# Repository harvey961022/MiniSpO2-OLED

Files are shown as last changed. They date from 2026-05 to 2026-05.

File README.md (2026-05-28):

# ESP32 血氧心率 OLED 顯示器

這是一個用 ESP32 做的小型血氧心率顯示器。

目前螢幕是 0.96 吋 128x64 I2C OLED

* SpO2 血氧
* BPM 心率
* 感測器狀態
* 手指是否有放好

## 使用的硬體

* ESP32 / NodeMCU-32S
* MAX30102 或 MAX30105 血氧心率感測器
* 0.96 吋 OLED 顯示幕
  * 128x64
  * I2C / IIC
  * 4 Pin
  * 常見 SSD1306 驅動
* 杜邦線

## 接線方式

OLED 跟 MAX30102 / MAX30105 都是 I2C，所以可以接在同一組 SDA / SCL 上。

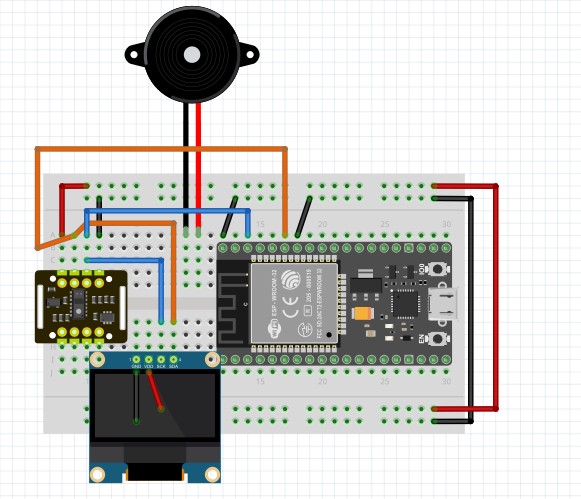
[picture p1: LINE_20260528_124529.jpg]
ESP32 血氧心率 OLED 接線圖


ESP32 常用接法：

```text
OLED VCC  -> 3V3 或 5V
OLED GND  -> GND
OLED SDA  -> GPIO 21
OLED SCL  -> GPIO 22

MAX30102 VCC -> 3V3 或 5V
MAX30102 GND -> GND
MAX30102 SDA -> GPIO 21
MAX30102 SCL -> GPIO 22
```

如果你的模組標示不是 SDA / SCL，而是其他名字，基本上也是照 I2C 腳位去接。

接線圖原始檔可以下載 `Oxygen_Saturation.fzz`，使用 Fritzing 開啟後可以自行修改。

## 需要安裝的 Library

Arduino IDE 裡面到：

```text
工具 -> 管理程式庫
```

然後搜尋並安裝下面這幾個。

### 1. Adafruit SSD1306

OLED 顯示幕用的 Library。

搜尋：

```text
Adafruit SSD1306
```

作者選 Adafruit。

### 2. Adafruit GFX Library

這是 OLED 畫文字、畫線、畫圖形會用到的核心 Library。

搜尋：

```text
Adafruit GFX Library
```

作者選 Adafruit。

### 3. Adafruit BusIO

Adafruit 的顯示相關 Library 常常會用到這個。

搜尋：

```text
Adafruit BusIO
```

如果安裝 Adafruit SSD1306 的時候 Arduino IDE 問你要不要一起安裝依賴套件，直接選全部安裝就可以。

### 4. SparkFun MAX3010x Pulse and Proximity Sensor Library

這個是 MAX30102 / MAX30105 血氧心率感測器用的。

搜尋：

```text
SparkFun MAX3010x Pulse and Proximity Sensor Library
```

作者選 SparkFun。

程式裡會用到：

```cpp
#include "MAX30105.h"
#include "heartRate.h"
```

所以這個一定要裝。

## ESP32 開發板套件

如果 Arduino IDE 還沒有 ESP32 開發板，需要先安裝 ESP32 Board Package。

到：

```text
工具 -> 開發板 -> 開發板管理員
```

搜尋：

```text
esp32
```

安裝：

```text
esp32 by Espressif Systems
```

開發板可以選：

```text
NodeMCU-32S
```

## OLED 位址

這種 0.96 吋 I2C OLED 最常見的位址是：

```cpp
#define OLED_ADDR 0x3C
```

如果燒錄後 OLED 沒畫面，可以試著改成：

```cpp
#define OLED_ADDR 0x3D
```

通常不是 `0x3C` 就是 `0x3D`。

## 上傳時如果卡在 Connecting

ESP32 有時候不會自動進入燒錄模式，會出現類似：

```text
Failed to connect to ESP32
Wrong boot mode detected
```

這不是程式錯，是板子沒有進 download mode。

解法：

1. 按 Arduino IDE 的上傳
2. 下面出現 `Connecting...` 的時候
3. 按住 ESP32 上的 `BOOT` 鍵
4. 等它開始燒錄後再放開

如果還是不行，可以先把上傳速度改成：

```text
115200
```

路徑：

```text
工具 -> Upload Speed -> 115200
```

## 編譯時出現 I2C_BUFFER_LENGTH warning

如果看到這個：

```text
warning: "I2C_BUFFER_LENGTH" redefined
```

可以先不用管。

這通常是 ESP32 的 Wire Library 跟 SparkFun MAX3010x Library 都有定義 I2C buffer，雖然會跳 warning，但不影響編譯，也不影響上傳。

只要最後有出現類似這種：

```text
草稿碼使用了 xxx bytes
全域變數使用了 xxx bytes
```

代表程式已經編譯成功。

## 使用方式

1. 接好 OLED 跟 MAX30102 / MAX30105
2. 開啟 Arduino IDE
3. 選擇開發板 `NodeMCU-32S`
4. 選擇正確的 COM Port
5. 按上傳
6. 燒錄完成後，把手指放到感測器上
7. OLED 會顯示血氧跟心率

## 注意事項

這個是 DIY 測試用的血氧心率顯示器，不是醫療設備。

數值會受到很多東西影響，例如：

* 手指有沒有放好
* 手指有沒有晃動
* 感測器壓太緊或太鬆
* 環境光太強
* 模組品質
* 電源是否穩定

所以數值可以拿來參考，但不能當成醫療判斷依據。

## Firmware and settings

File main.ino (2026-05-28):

#include <Wire.h>
#include <Adafruit_GFX.h>
#include <Adafruit_SSD1306.h>
#include "MAX30105.h"
#include "heartRate.h"


#ifndef IRAM_ATTR
#define IRAM_ATTR
#endif

//螢幕
#define SCREEN_WIDTH 128
#define SCREEN_HEIGHT 64
#define OLED_RESET -1
#define OLED_ADDR 0x3C

Adafruit_SSD1306 display(SCREEN_WIDTH, SCREEN_HEIGHT, &Wire, OLED_RESET);

//初始
const int Tonepin = 4; 
MAX30105 particleSensor;
bool oledReady = false;
bool sensorReady = false;

// 血氧
#define FINGER_ON 7000          
#define MINIMUM_SPO2 90.0   

const byte RATE_SIZE = 8;
byte rates[RATE_SIZE];
byte rateSpot = 0;
byte validRateCount = 0;
long lastBeat = 0;
float beatsPerMinute = 0;
int beatAvg = 0;

int sampleCount = 0;
const int numSamples = 30;
double avered = 0, aveir = 0;
double sumirrms = 0, sumredrms = 0;
double SpO2 = 0, ESpO2 = 90.0;
const double FSpO2 = 0.7;
const double frate = 0.95;

unsigned long lastDisplayUpdate = 0;
const unsigned long DISPLAY_INTERVAL = 250; // 刷新250ms

// 工具
void resetReadings() {
  for (byte i = 0; i < RATE_SIZE; i++) rates[i] = 0;
  rateSpot = 0;
  validRateCount = 0;
  lastBeat = 0;
  beatsPerMinute = 0;
  beatAvg = 0;

  sampleCount = 0;
  avered = 0;
  aveir = 0;
  sumirrms = 0;
  sumredrms = 0;
  SpO2 = 0;
  ESpO2 = 90.0;
}

void printCentered(const char *text, int y, int textSize) {
  display.setTextSize(textSize);
  int16_t x1, y1;
  uint16_t w, h;
  display.getTextBounds(text, 0, y, &x1, &y1, &w, &h);
  display.setCursor((SCREEN_WIDTH - w) / 2, y);
  display.print(text);
}

void drawBootScreen(const char *line1, const char *line2) {
  if (!oledReady) return;
  display.clearDisplay();
  display.setTextColor(SSD1306_WHITE);
  printCentered(line1, 16, 1);
  printCentered(line2, 34, 1);
  display.display();
}

void drawMainScreen(bool fingerOn) {
  if (!oledReady) return;

  display.clearDisplay();
  display.setTextColor(SSD1306_WHITE);
  display.setTextWrap(false);

  if (!fingerOn) {
    printCentered("PULSE OXIMETER", 2, 1);
    display.drawFastHLine(0, 13, 128, SSD1306_WHITE);
    printCentered("PLACE FINGER", 26, 1);
    printCentered("ON SENSOR", 42, 1);
    display.display();
    return;
  }

  display.setTextSize(1);
  display.setCursor(0, 0);
  display.print("SpO2");
  display.setCursor(93, 0);
  display.print("BPM");
  display.drawFastHLine(0, 10, 128, SSD1306_WHITE);

  display.setTextSize(3);
  display.setCursor(0, 20);
  if (beatAvg > 30 && ESpO2 >= 90.0) {
    display.print((int)(ESpO2 + 0.5));
  } else {
    display.print("--");
  }

  display.setTextSize(2);
  display.setCursor(48, 28);
  display.print("%");

  display.drawFastVLine(70, 12, 52, SSD1306_WHITE);
  display.setTextSize(3);
  display.setCursor(78, 20);
  if (beatAvg > 0) {
    if (beatAvg < 100) display.print(" ");
    display.print(beatAvg);
  } else {
    display.print("--");
  }


  display.setTextSize(1);
  display.setCursor(0, 56);
  if (beatAvg > 30) {
    display.print("Keep still");
  } else {
    display.print("Measuring...");
  }


  if (millis() - lastBeat < 180) {
    display.fillCircle(122, 58, 3, SSD1306_WHITE);
  } else {
    display.drawCircle(122, 58, 3, SSD1306_WHITE);
  }

  display.display();
}

void setup() {
  Serial.begin(115200); 

  oledReady = display.begin(SSD1306_SWITCHCAPVCC, OLED_ADDR);
  if (oledReady) {
    display.clearDisplay();
    display.setTextColor(SSD1306_WHITE);
    drawBootScreen("Hello", "Starting...");
  } else {
    Serial.println("OLED not found. Check I2C address/wiring.");
  }

  if (!particleSensor.begin(Wire, I2C_SPEED_FAST)) {
    Serial.println("MAX30105 was not found. Check wiring/power.");
    drawBootScreen("SENSOR ERROR", "CHECK WIRING");
    return;
  }

  sensorReady = true;

  // ledBrightness, sampleAverage, ledMode, sampleRate, pulseWidth, adcRange
  particleSensor.setup(0x7F, 4, 2, 800, 215, 16384);
  particleSensor.enableDIETEMPRDY();
  particleSensor.setPulseAmplitudeRed(0x24);
  particleSensor.setPulseAmplitudeIR(0x24);
  particleSensor.setPulseAmplitudeGreen(0);

  delay(800);
  drawMainScreen(false);
}

// mainloop
void loop() {
  if (!sensorReady) {
    delay(1000);
    return;
  }

  long irValue = particleSensor.getIR();
  bool fingerOn = (irValue > FINGER_ON);

  if (fingerOn) {
    if (checkForBeat(irValue)) {
      long delta = millis() - lastBeat;
      lastBeat = millis();

      beatsPerMinute = 60.0 / (delta / 1000.0);

      if (beatsPerMinute > 20 && beatsPerMinute < 255) {
        rates[rateSpot++] = (byte)beatsPerMinute;
        rateSpot %= RATE_SIZE;
        if (validRateCount < RATE_SIZE) validRateCount++;

        int total = 0;
        for (byte i = 0; i < validRateCount; i++) total += rates[i];
        beatAvg = total / validRateCount;

        tone(Tonepin, 1000, 10);
      }
    }

    
    particleSensor.check();
    while (particleSensor.available()) {
      uint32_t red = particleSensor.getFIFORed();
      uint32_t ir = particleSensor.getFIFOIR();

      double fred = (double)red;
      double fir = (double)ir;

      avered = avered * frate + fred * (1.0 - frate);
      aveir = aveir * frate + fir * (1.0 - frate);

      sumredrms += (fred - avered) * (fred - avered);
      sumirrms += (fir - aveir) * (fir - aveir);

      sampleCount++;
      if (sampleCount >= numSamples) {
        if (avered > 0 && aveir > 0 && sumirrms > 0) {
          double R = (sqrt(sumredrms) / avered) / (sqrt(sumirrms) / aveir);
          SpO2 = -23.3 * (R - 0.4) + 100.0;
          ESpO2 = FSpO2 * ESpO2 + (1.0 - FSpO2) * SpO2;

          if (ESpO2 <= MINIMUM_SPO2) ESpO2 = MINIMUM_SPO2;
          if (ESpO2 > 100.0) ESpO2 = 99.9;
        }

        sumredrms = 0.0;
        sumirrms = 0.0;
        sampleCount = 0;
      }

      particleSensor.nextSample();
    }
  } else {
    resetReadings();
  }

  if (millis() - lastDisplayUpdate >= DISPLAY_INTERVAL) {
    drawMainScreen(fingerOn);
    lastDisplayUpdate = millis();
  }
}

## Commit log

2026-05-28 Add ESP32 oximeter OLED project
2026-05-28 Add wiring diagram assets
    [Oxygen_Saturation.fzz]
